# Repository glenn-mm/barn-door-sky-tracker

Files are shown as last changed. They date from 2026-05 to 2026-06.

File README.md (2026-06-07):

# Isoceles Barndoor Sky Tracker
## Parts
* See bom.csv for parts list
* 3D printed parts use 20% infill
* Two of the following parts will need to be printed:
  * Part 2
  * Part 3
  * Part 5
  * Part 12

## Build Instructions
### Tools
1. M4x0.7 tap
2. Pliers
3. M2.5 allen key
4. Phillips head screw driver

### Steps
1. Print parts and acquire hardware per bom.csv
2. Clean up 3d printed parts
    1. Ensure gears are free of support material
    2. Ensure Part 6 has all internal support material removed
3. Tap threads into Part 6 and 10

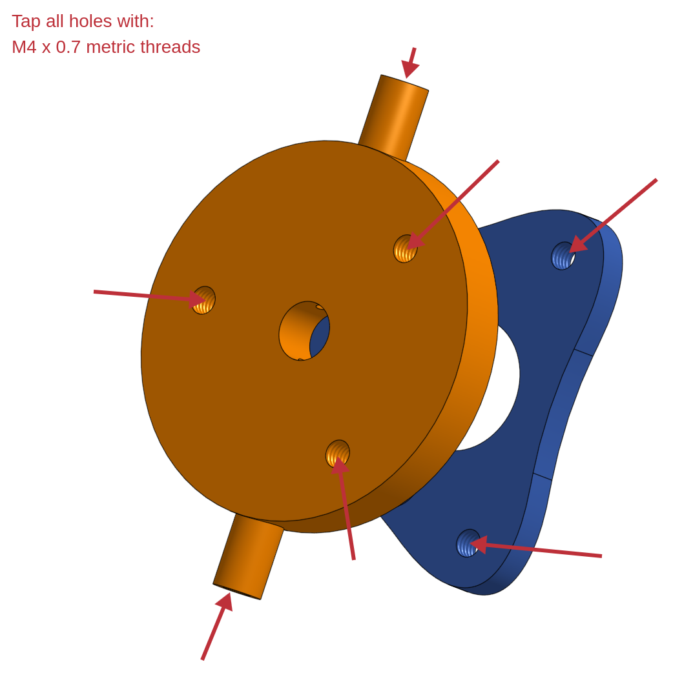
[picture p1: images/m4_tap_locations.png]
M4 tap locations


4. Begin assembly of pivot with Part 2 and 3
   1. Bearing is fit between parts per diagram

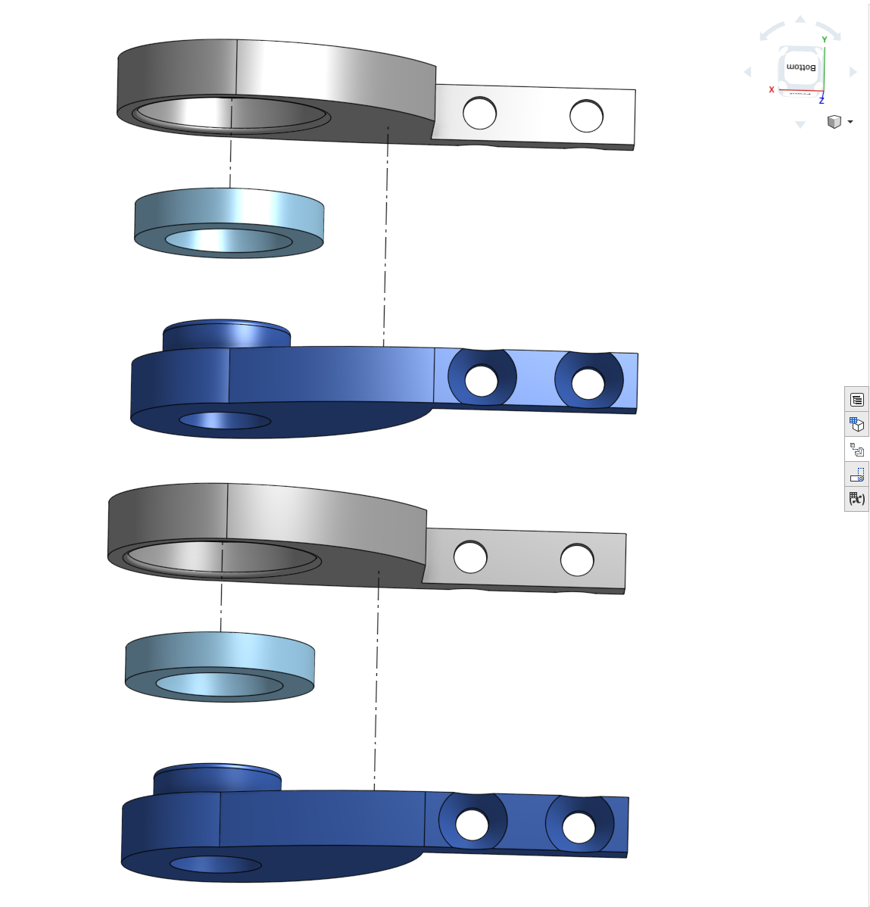
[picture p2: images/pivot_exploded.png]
Pivot Exploded


5. Begin motor assembly with Part 5, 6, 9, 10, 11, 12 and spur center

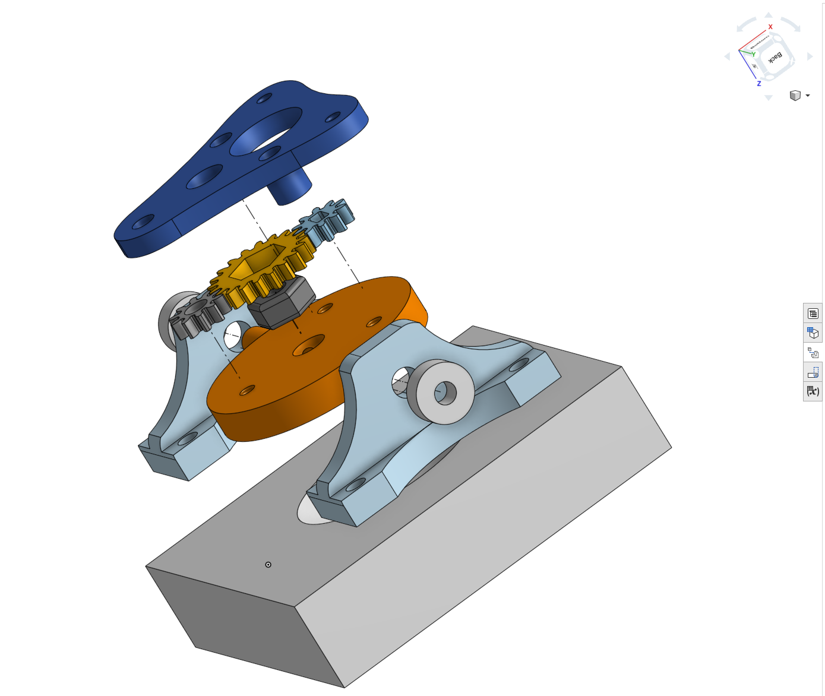
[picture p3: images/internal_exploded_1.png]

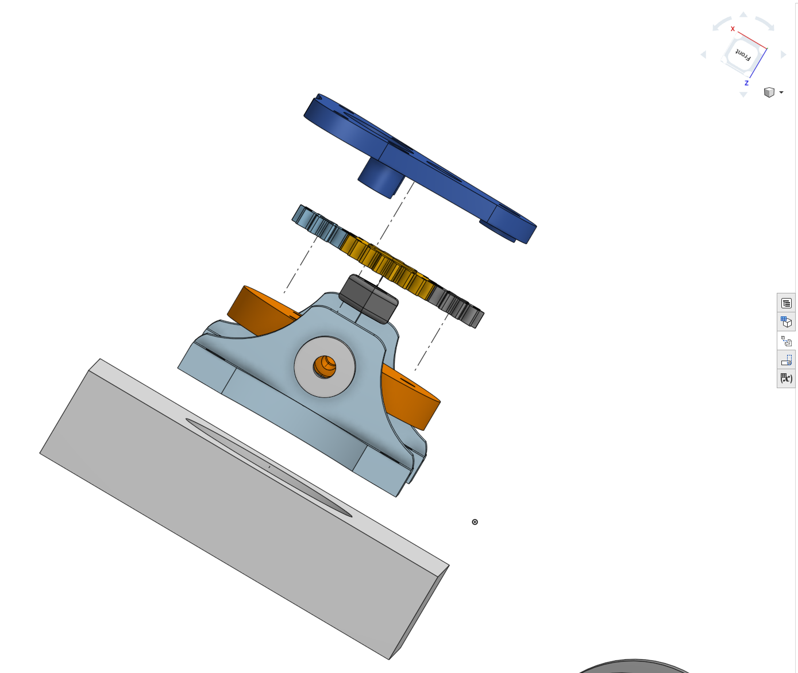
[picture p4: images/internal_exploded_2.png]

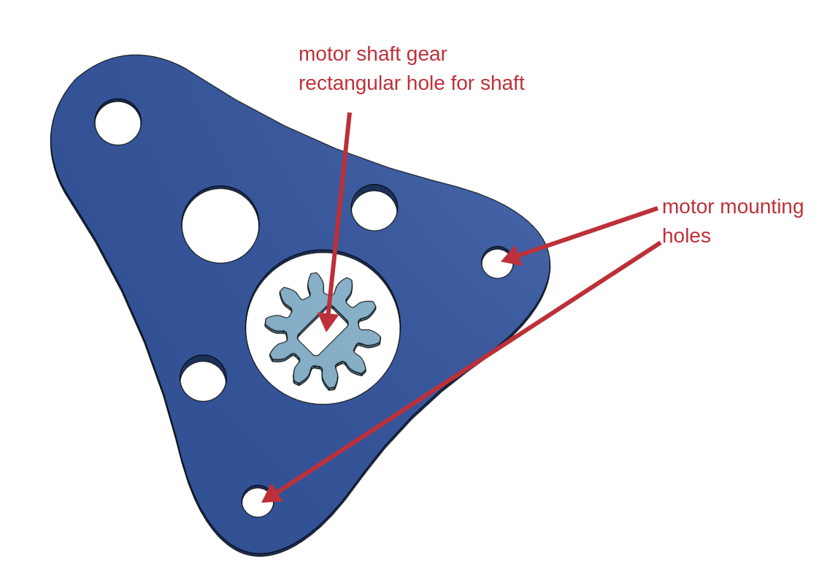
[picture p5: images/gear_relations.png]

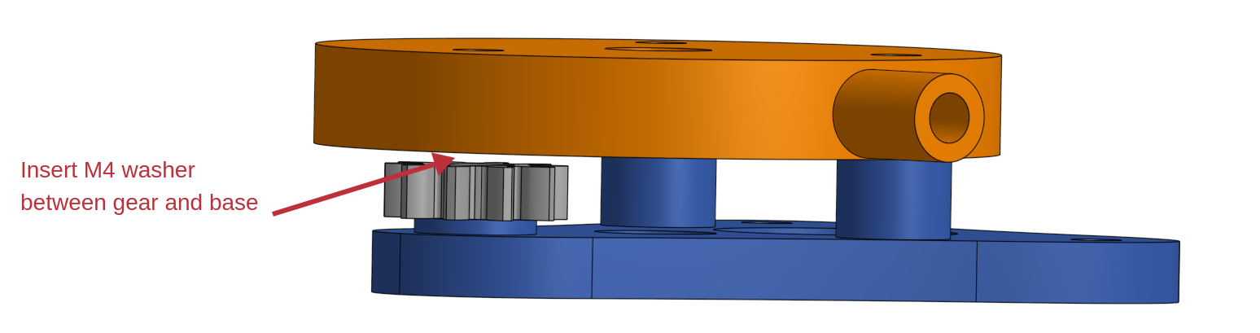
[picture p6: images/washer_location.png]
M4 washer location

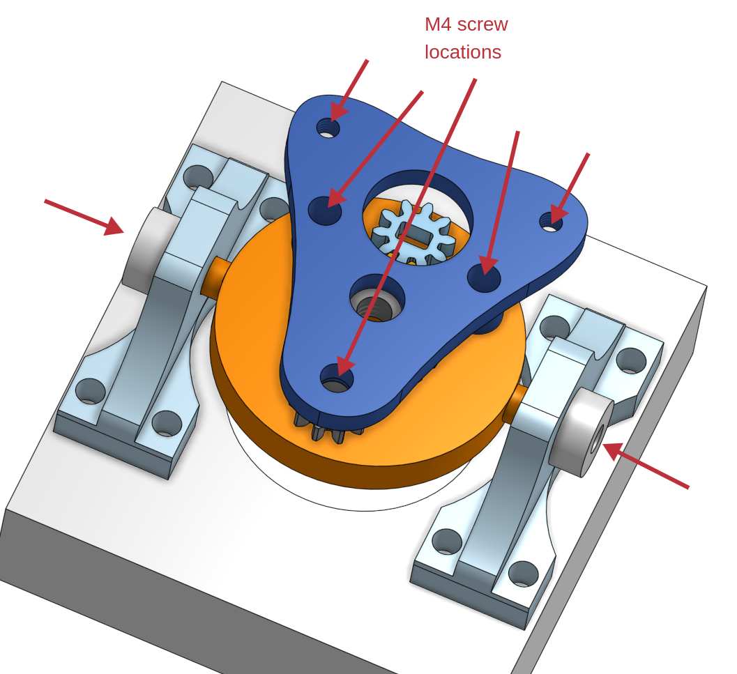
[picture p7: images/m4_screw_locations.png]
M4 screw locations

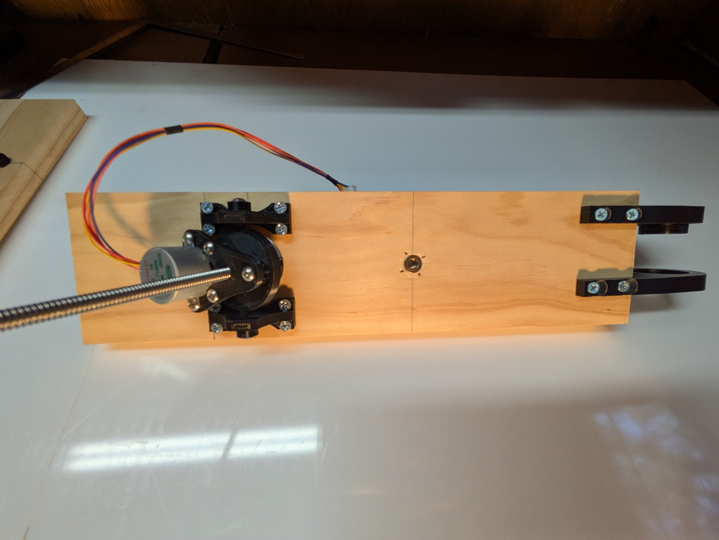
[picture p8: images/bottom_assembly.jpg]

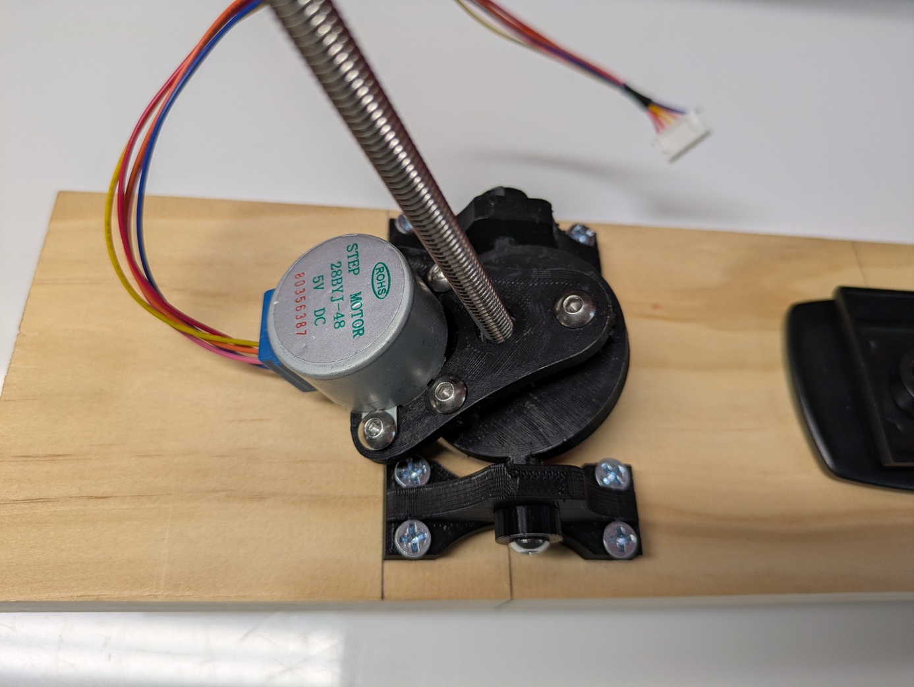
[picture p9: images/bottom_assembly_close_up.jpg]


6. Attach 1/4 round cap to 1/4-20 threaded rod
   1. Use thread locker red or an adhesive that works on metal

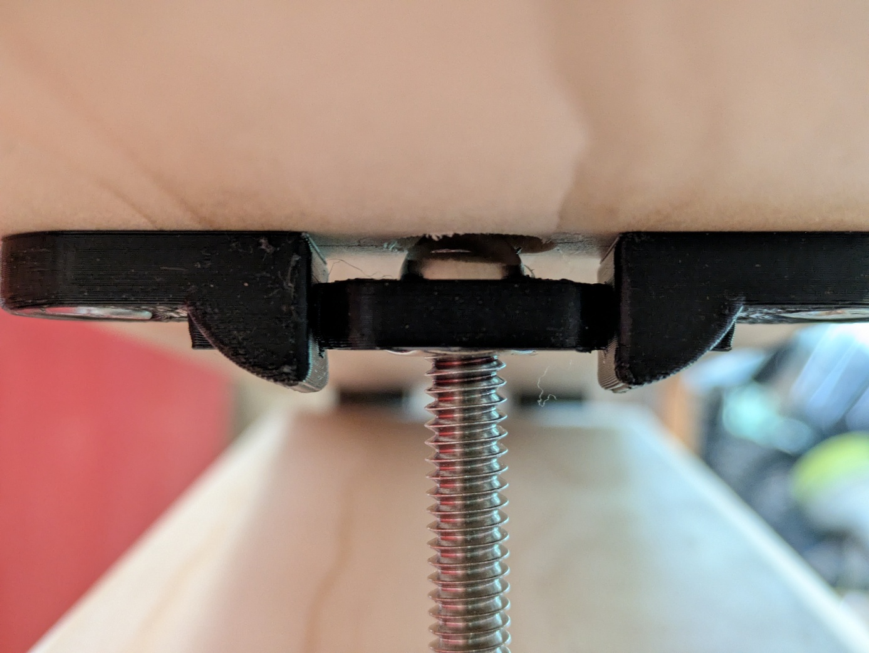
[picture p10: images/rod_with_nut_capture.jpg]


7. Wooden components
   1. Primary concern with wooden components is that the motor relative to pivot is 29 cm (see math section below)
   2. Dimensions in mm, closest imperial equivalent is good enough (**stock must be 3/4" for pivot**)

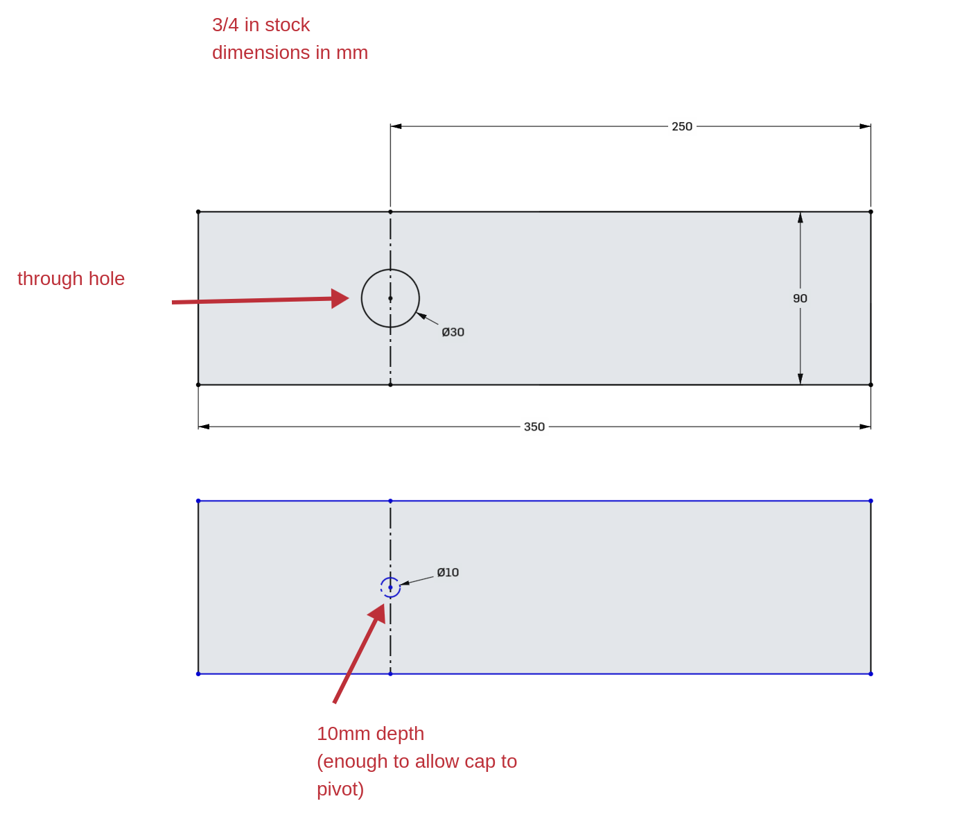
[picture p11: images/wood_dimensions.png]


8. Electronics wiring as below
   1. Setup Arduino IDE for Nano board
      1. https://docs.arduino.cc/tutorials/nano/nano-getting-started/
   2. Electrical connections diagram below
   3. Open barn-door-tracker.ino in Arduino IDE and upload to board

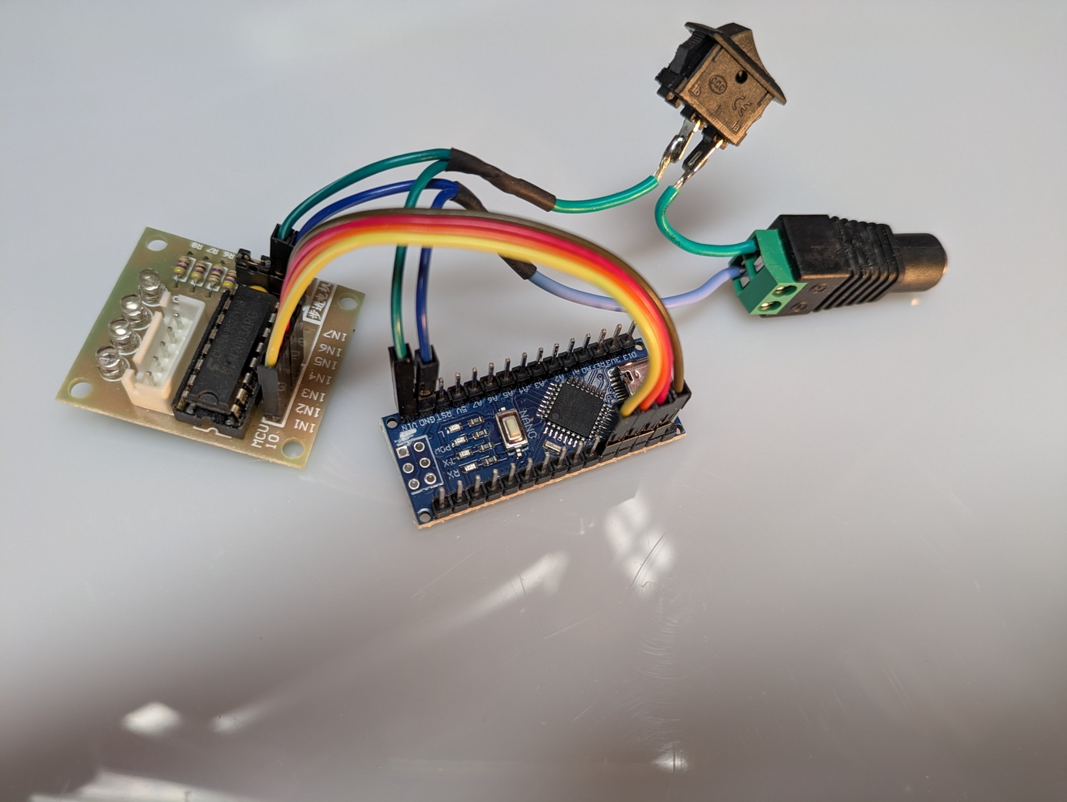
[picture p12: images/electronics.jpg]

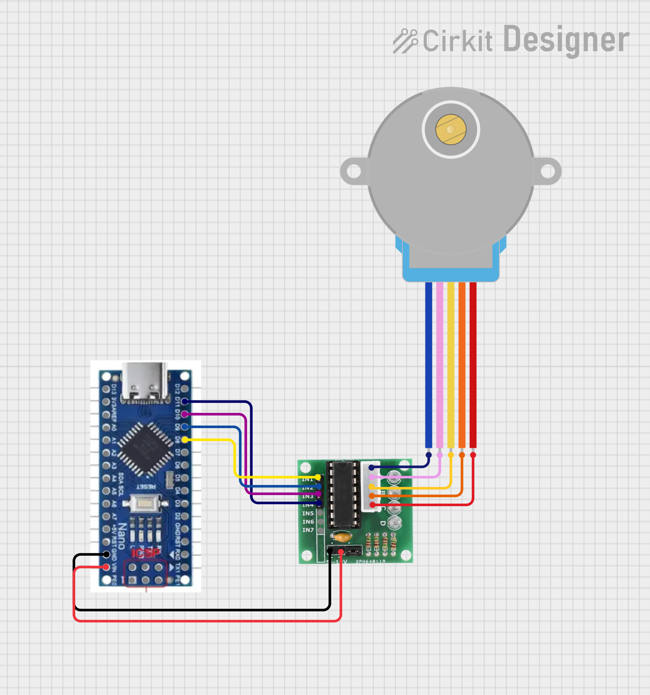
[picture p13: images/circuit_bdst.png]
Electrical Diagram


### Math
To support tracking the stars we need a few constants:

* Sidereal day (https://en.wikipedia.org/wiki/Sidereal_time)
  * 86164.09056 (seconds)
* Law of Cosines (https://en.wikipedia.org/wiki/Law_of_cosines)
```math
c^2 = a^2 + b^2 - 2ab \cos(\theta)
```
Solved for the third side knowing two sides and an angle
```math
c = \sqrt{a^2 + b^2 - 2ab \cos(\theta)}
```

* Steps per full rotation in 28BYJ-48 at full stepping mode
  * 2048 (4096 for half stepping mode)
* Rotations per cm of rod extension
  * 7.874
* Length of two sides
  * 29 cm

Now we solve for time over which the instrument is running.  Assumes starting angle is effectively zero (not entirely true, but close enough).

Radians per second $`(R) = 2 * \pi / 86164.09056`$

Radians at Time T $`R(T) = T * ( 2 * \pi / 86164.09056 )`$

Bolt extension (cm/T) $`B(T) = \sqrt{29^2+29^2-2*29*29*\cos(R(T))}`$

Rotations at Time T $`Rot(T) = B(T)/7.874cm`$

Solving for time T our steps per second comes out to ~66.00355.  This means we can drive the motor at 66 steps per second over the duration of the bolt and fine, but also means we need to get the 29cm side length correct!

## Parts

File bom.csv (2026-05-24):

Part | Description | Quantity | Link
 | 3D printed parts (see zip with stl/step files) | 1 | github
 | 6805-SR bearing | 2 | https://www.amazon.com/dp/B082PYT33D
 | 1” x 3” x 36” select pine board | 2 | hardware store
 | 1/4in-20 nut | 1 | hardware store
 | 1/4in-20 bolt | 1 | https://www.amazon.com/dp/B0D9L9CK7S
 | M4 x 12 screws | 5 | https://www.amazon.com/dp/B0FR2SWJQ6?th=1
 | #8 x ¾” | 8 | hardware store
 | #10 x 1” | 8 | hardware store
 | F to F dupont wire breadboard jumper | 1 | https://www.amazon.com/dp/B0BRTKTV64
 | 28BYJ-48 ULN2003 5V stepper motor | 1 | https://www.amazon.com/dp/B01CP18J4A
 | Arduino nano | 1 | https://www.amazon.com/dp/B0DXDTD83X

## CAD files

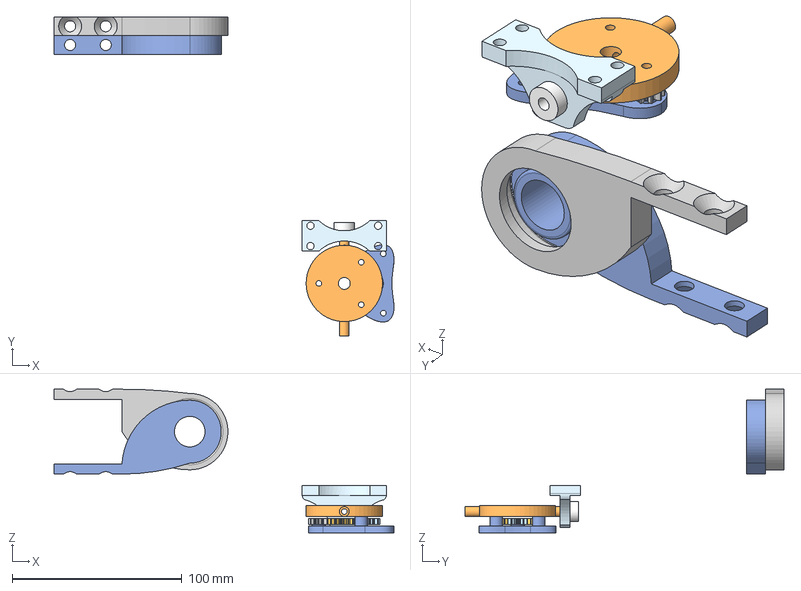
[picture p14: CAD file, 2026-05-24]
parts/3dp_parts.step
200.3 x 188.0 x 84.6 mm
spur center

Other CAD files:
parts/3dp_parts.3mf

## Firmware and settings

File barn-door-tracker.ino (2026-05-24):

#include "AccelStepper.h"

// Motor pin definitions:
#define motorPin1  8      // IN1 on the ULN2003 driver
#define motorPin2  9      // IN2 on the ULN2003 driver
#define motorPin3  10     // IN3 on the ULN2003 driver
#define motorPin4  11     // IN4 on the ULN2003 driver

// Initialize with pin sequence IN1-IN3-IN2-IN4 for using the AccelStepper library with 28BYJ-48 stepper motor:
AccelStepper stepper = AccelStepper(AccelStepper::FULL4WIRE, motorPin1, motorPin3, motorPin2, motorPin4);

void setup() {
  // Set the maximum steps per second:
  stepper.setMaxSpeed(67);
    // Set the current position to 0:A
  stepper.setCurrentPosition(0);
  // Run the motor forward at 66 steps/second
  stepper.setSpeed(66);
}

void loop() {
  stepper.runSpeed();
}

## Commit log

2026-05-24 initial commit with files for build and code
    [3dp_parts.3mf, 3dp_parts.step, bom.csv]
2026-06-01 initial verson of instructions with images
    [3dp_parts.3mf, 3dp_parts.step]
2026-06-07 Adding notes on math and Arduino IDE setup
